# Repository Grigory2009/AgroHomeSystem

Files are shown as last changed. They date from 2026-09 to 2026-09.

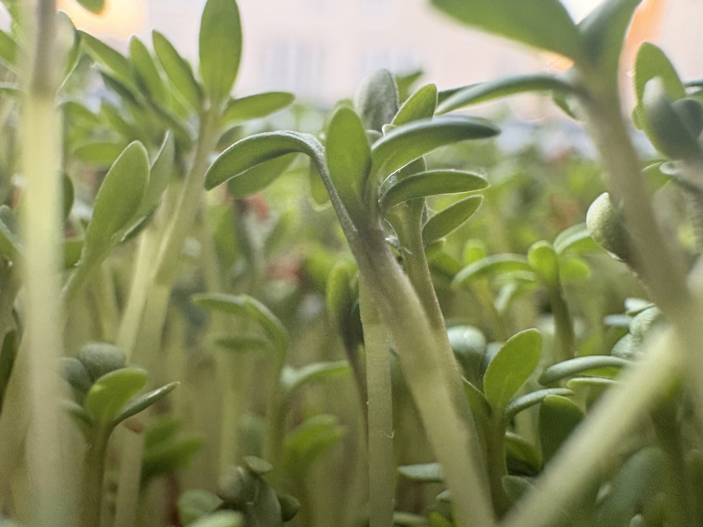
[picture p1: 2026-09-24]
demo/real_test_dataset/cress_mature_tray.jpg

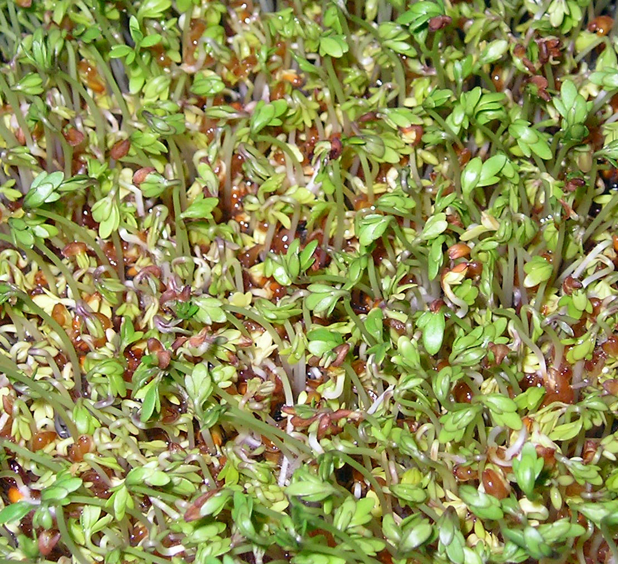
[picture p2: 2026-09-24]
demo/real_test_dataset/cress_seedling_vdg.jpg

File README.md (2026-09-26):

# 🌱 AgroHomeSystem: Автономный модульный агро-инкубатор с машинным зрением

<div align="center">








<br/>

**Компактная роботизированная экосистема прецизионного выращивания микрозелени, проращивания семян и черенкования на основе гидропоники периодического затопления, локального сенсорного контроля, спектрального распознавания желтой минеральной ваты и нейросетевой аналитики здоровья растений.**

[О проекте](#-о-проекте) • [Ключевые инновации](#-ключевые-инновации) • [Архитектура](#-архитектура-системы) • [Механика и 3D-конструкция](#-механика-и-3d-конструкция) • [Гидропоника и сенсоры](#-гидропоника-и-сенсорная-подсистема) • [Прошивка ESP32-S3 & OTA](#-прошивка-и-интерфейс-esp32-s3) • [Компьютерное зрение и 24 ячейки](#-компьютерное-зрение-и-edge-ai) • [Быстрый старт](#-быстрый-старт) • [AI Context](#-контекст-для-ии-project_contextmd)

</div>

---

## 📌 О проекте

**AgroHomeSystem** — это автономный программно-аппаратный комплекс (инкубатор), созданный для решения фундаментальных проблем закрытого растениеводства: высоких трудозатрат, нестабильности микроклимата, шума вентиляционных установок и позднего обнаружения болезней растений.

Устройство выполнено в ультракомпактном форм-факторе **260×200 мм** (ревизия корпуса **v2**) и оснащено съемным лотком на **24 изолированные посадочные ячейки** (сетка 4×6) под цилиндрические пробки из **минеральной ваты 22 мм**. В каждой ячейке поддерживается контролируемая корневая и надземная среда.

```
┌────────────────────────────────────────────────────────────────────────┐
│                        AGROHOMESYSTEM ECOSYSTEM                        │
├─────────────────────────┬─────────────────────────┬────────────────────┤
│   🤖 РОБОТИЗИРОВАННЫЙ   │     🌊 ГИДРОПОНИКА     │   👁️ КОМПЬЮТЕРНОЕ  │
│       МИКРОКЛИМАТ       │      EBB & FLOW         │        ЗРЕНИЕ      │
│  ПИД-купол с серво /    │ Автоматическое          │ Поячеечный трекинг │
│  NEMA17 проветриванием  │ периодическое           │ 24 ячеек (4x6) +   │
│  вместо шумных кулеров  │ затопление 24 ячеек     │ детекция минваты   │
├─────────────────────────┼─────────────────────────┼────────────────────┤
│   🖥️ ESP32-S3 TOUCH UI │    📈 ТЕЛЕМЕТРИЯ И VPD  │  ⚡ БЕСПРОВОДНАЯ   │
│  TFT 320x240, 4 вкладки │ pH, TDS, VPD, t° воды,  │   ПРОШИВКА (OTA)   │
│  AI экран, сброс уровня │ t° воздуха, влажность   │ Web /update &      │
│  Тамагочи-питомец       │ и Ebb & Flow таймер     │ ArduinoOTA (3232)  │
└─────────────────────────┴─────────────────────────┴────────────────────┘
```

---

## 💡 Ключевые инновации

### 1. Активный динамический купол с ПИД-проветриванием
В классических гроубоксах используются шумные вентиляторы, создающие сквозняки и сушащие нежные побеги. В **AgroHomeSystem** крышка модуля соединена с сервоприводом высокого крутящего момента. ПИД-регулятор микроконтроллера приоткрывает купол на строго выверенный угол, обеспечивая плавную конвекцию и удаление избытка тепла/влажности без вибраций и шума.

### 2. Прецизионное периодическое затопление 24 ячеек (Ebb & Flow)
Корневая система каждого растения размещается в индивидуальных пробках из минеральной ваты 22 мм в 24 посадочных гнездах. Встроенная микропомпа подает питательный раствор в верхний лоток, равномерно затапливая все 24 ячейки на 15 минут, после чего раствор самотеком сливается обратно в нижний резервуар, естественным образом насыщая корни кислородом.

### 3. Компьютерное зрение и спектральная детекция желтой минеральной ваты
Модуль `demo/cell_tracker.py` оснащен алгоритмами спектрального анализа:
- **Распознавание желтой минеральной ваты (22 мм Rockwool plugs):** субстрат точно идентифицируется по спектру $HSV$ и низкому индексу хлорофилла $\text{ExG} < 24$. Лоток со свежими пробками помечается как `🟡 ROCKWOOL (Готово к посеву)` со 100% здоровьем, исключая ложные тревоги хлороза и плесени.
- **Интеллектуальное автообнаружение лотка (`autodetect_tray`):** алгоритм автоматически находит круглые желтые пробки минеральной ваты на кадре с камеры, вычисляет границы прямоугольника рабочей зоны (ROI) и центрирует матрицу ячеек.
- **Интерактивная калибровка и ручной ввод:** в веб-дашборде доступно модальное окно с ползунками ROI, выбором рядов/колонок, а также карточки ручного редактирования сорта культуры (напр. *"Базилик"*, *"Руккола"*), даты посева и заметок с автосохранением в `demo/cell_grid_config.json`.

### 4. Двухстадийный Edge AI пайплайн диагностики
- **MobileNetV2 Watercress Edition (ONNX ARM NEON):** классификация фаз развития (*Прорастание → Семядоли → Спелая микрозелень*) и патологий (*Черная ножка Pythium, Серая гниль Botrytis, Хлороз Fe/N, Краевой ожог TDS*).
- **Биофизический спектральный сегментатор (ExG + HSV):** расчет площади листового полога (Biomass %), индексов хлорофилла, некроза и очагов плесени.

### 5. Беспроводная прошивка ESP32-S3 (Dual OTA)
Обновление микроконтроллера без подключения кабеля:
1. **Web OTA (`/update`):** Прошивка бинарника через браузер с киберпанк-индикатором и отображением прогресс-бара прямо на экране ST7789.
2. **ArduinoOTA (порт 3232):** Прямая заливка из PlatformIO / CLI (`pio run -t upload --upload-port <IP>`).

---

## 🏗️ Архитектура системы

```mermaid
graph TD
    subgraph "Физический инкубатор v2 (260x200 мм)"
        Lid["Активный купол с сервоприводом"]
        Cam["Широкоугольная камера (внутри крышки)"]
        Tray["Лоток на 24 ячейки (4x6 под 22 мм минвату)"]
        Pump["Микро-помпа затопления 12V"]
        Sensors["Сенсоры: pH 4502C, TDS, DS18B20 (t°воды), BME280 (t°возд/RH/VPD)"]
        TFT["2.8' TFT Touch LCD (ILI9341 + XPT2046)"]
    end

    subgraph "Узел управления (ESP32-S3 Dual OTA)"
        FreeRTOS["FreeRTOS (Двухъядерный режим)"]
        PID["ПИД-контроллер купола & Таймер помпы"]
        UI_Engine["Touch UI: 4-вкладочный навбар, AI экран, Тамагочи"]
        WebOTA["Web OTA (/update) & ArduinoOTA (3232)"]
    end

    subgraph "Edge AI Hub (Raspberry Pi 4B / Host PC)"
        MobileNet["MobileNetV2 ONNX (Кресс-салат & 38 патологий)"]
        ExG["ExG + HSV Спектральный сегментатор"]
        CellTracker["GridCellTracker (24 ячейки + детекция минваты)"]
        Bridge["EspBridge (UART 115200 / Wi-Fi REST)"]
        WebDash["Единый Web Dashboard (порт 8080, MJPEG, SPA)"]
        ConfigJSON["cell_grid_config.json (Персистентность)"]
    end

    Sensors -->|Аналог / I2C / 1-Wire| FreeRTOS
    FreeRTOS --> PID --> Lid & Pump
    FreeRTOS --> UI_Engine --> TFT
    Cam -->|USB / CSI Video Stream| MobileNet & ExG & CellTracker
    CellTracker <--> ConfigJSON
    MobileNet & ExG & CellTracker --> Bridge --> WebDash
    Bridge <-->|USB Serial / Wi-Fi| FreeRTOS
```

---

## 📐 Механика и 3D-конструкция

Все механические элементы спроектированы для 3D-печати пластиками PETG / ABS / ASA и доступны в **Компас-3D** и формате **STEP**:

| 3D-модель (STEP в `hardware/cad/step/`) | Назначение детали | Особенности конструкции |
|:---|:---|:---|
| **`Корпус нижняя часть v2.stp`** | Обновленный базовый корпус-резервуар (260×200 мм) | Двойное дно: отсек гидропонного раствора + дренажный уклон, отсек электроники и экрана, петли купола. |
| **`Ячейки.stp`** | Съемный посадочный лоток на 24 ячейки (сетка 4×6) | 24 посадочных гнезда под стандартные минераловатные пробки 22 мм (Grodan / BelAgro). |
| **`Крышка - Деталь.stp`** | Активный прозрачный/светозащитный купол | Крепление широкоугольной камеры, аэродинамические направляющие проветривания, проушины петель. |
| **`22мм .stp`** / **`22 мм мин вата.stp`** | Посадочные картриджи ячеек | Калибровочные вставки под субстратные пробки 22 мм. |
| **`держатель.stp`** | Кронштейн привода и сенсорной корзины | Универсальное крепление для сервопривода купола и платы контроллера. |
| **`угол.stp`** | Силовые угловые замки | Фиксация геометрии лотка, предотвращение деформаций при термоциклировании. |
| **`Штырь 10мм / 9мм - Деталь.stp`** | Оси поворотных петель крышки | Износостойкие поворотные штифты с фиксацией без люфтов. |

```
                 Крышка с камерой и серво-приводом
                    ┌─────────────────────────┐  ◄── Открытие по ПИД
                    ╱                         ╱│      на угол 0°..65°
                   ┌─────────────────────────┐ │
                   │ [A1][A2][A3][A4]        │ │  ◄── 24 ячейки под
                   │ [B1][B2][B3][B4]        │ │      минеральную вату
                   │ [C1][C2][C3][C4]        │ │      22 мм (v2)
                   │ [D1][D2][D3][D4]        │ │
                   │ [E1][E2][E3][E4]        │ │
                   │ [F1][F2][F3][F4]        │ │
                   ├─────────────────────────┤ │
                   │ Резервуар Ebb & Flow    │╱   ◄── Габариты: 260 х 200 мм
                   └─────────────────────────┘
```

---

## 💧 Гидропоника и сенсорная подсистема

Система реализует автоматический замкнутый цикл гидропонного питания **Ebb and Flow**:

1. **Фаза затопления (15 минут):** Микропомпа поднимает питательный раствор из нижнего бака в зону корней 24 ячеек. Пробки из минеральной ваты напитываются сбалансированным раствором.
2. **Фаза аэрации / осушения (45 минут):** Помпа отключается, раствор самотеком возвращается в нижний резервуар через сливные отверстия. Отступающая жидкость затягивает свежий кислород внутрь пор минваты.
3. **Контролируемые параметры среды:**
   - **pH раствора:** целевой диапазон **5.5 – 6.8** (сенсор 4502C).
   - **TDS / EC (Минерализация):** целевой диапазон **400 – 950 ppm**.
   - **Температура раствора:** целевой диапазон **18.0 – 22.0 °C** (сенсор DS18B20).
   - **Температура и влажность воздуха:** сенсор BME280.
   - **Дефицит упругости водяного пара (VPD):** целевой диапазон **0.6 – 1.1 кПа**.

---

## 💻 Прошивка и интерфейс ESP32-S3

Прошивка микроконтроллера разработана в среде **PlatformIO (Arduino Framework / FreeRTOS)** для чипа **ESP32-S3 DevKitM-1** (`firmware/src/main.cpp`).

- **Дисплей:** 2.8-дюймовый SPI TFT 320×240 (ILI9341) с резистивной тач-панелью XPT2046.
- **4-вкладочный интерфейс:**
  - `[МОНИТОР]` — гидропоника, датчики pH/TDS/климата, ручной полив.
  - `[ИИ ЗРЕНИЕ]` — данные с камеры от Raspberry Pi: статус здоровья, 4-сегментный прогресс-бар фаз роста, биомасса, диагноз и агро-рекомендации.
  - `[РОСТОК]` — виртуальный питомец («Тамагочи»), забота, полив, кнопка сброса уровня прогресса.
  - `[НАСТРОЙКИ]` — темы (`Cyber Emerald`, `Nordic Ice`, `Solar Amber`), Wi-Fi, OTA, выбор языка (RU/EN).
- **Беспроводная прошивка (Dual OTA):** Web-программатор на `/update` и ArduinoOTA (порт 3232).

---

## 👁️ Компьютерное зрение и Edge AI

В папке `demo/` реализован полный комплекс нейросетевой диагностики и поячеечного трекинга:

- **`cell_tracker.py`** — Движок индивидуального трекинга 24 ячеек (4×6):
  - Спектральная детекция желтой минеральной ваты ($HSV$ + $\text{ExG} < 24$);
  - Компьютерное зрение автообнаружения лотка по пробкам (`autodetect_tray`);
  - Расчет покрытия пологом (Biomass %), хлороза, некроза, плесени;
  - Киберпанк HUD-оверлей с неоновыми кольцами и бейджами ячеек.
- **`web_dashboard.py`** — Единый SPA веб-дашборд на порту 8080:
  - Живой MJPEG видеопоток (режимы RGB, ExG маска, Split, 24 Ячейки HUD);
  - Модальное окно калибровки геометрии матрицы (ползунки ROI, ряды, колонки, радиус);
  - Инспектор ячейки с ручным редактированием культуры, даты посадки, статуса и заметок;
  - Телеметрия сенсоров в реальном времени, управление помпой, выбор агропресетов.
- **`plant_health_engine.py`** — Мультимодальный движок классификации культур и болезней (MobileNetV2 ONNX + ExG сегментатор).
- **`esp_bridge.py`** — Двусторонний мост связи с ESP32-S3 (UART 115200 / Wi-Fi).

---

## 🚀 Быстрый старт

### Запуск на Raspberry Pi 4B:

```bash
# 1. Получить актуальную версию
cd ~/AgroHomeSystem
git pull origin main

# 2. Установить зависимости Python
cd demo
pip3 install -r requirements.txt

# 3. Запуск веб-дашборда с камерой и подключением к ESP32:
python3 web_dashboard.py --camera 0 --esp-port auto --port 8080
```

Веб-дашборд доступен в браузере по адресу: **`http://<IP_RPI>:8080`** или **`http://localhost:8080`**.

---

## 🧠 Контекст для ИИ (`PROJECT_CONTEXT.md`)

Для разработчиков и AI-ассистентов в корне репозитория создан файл **[`PROJECT_CONTEXT.md`](PROJECT_CONTEXT.md)**, содержащий полное описание архитектуры, протоколов связи, спектральных масок и REST API для мгновенной загрузки контекста в диалоге.

---

## 📜 Лицензия

* Аппаратная часть, прошивка и архитектура — **MIT License**.
* Модели компьютерного зрения — в соответствии с лицензиями **Apache 2.0**.

<div align="center">
  Разработано с заботой о растениях 🌿 • <b>AgroHomeSystem 2026</b>
</div>

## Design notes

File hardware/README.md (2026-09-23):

# 🛠️ AgroHomeSystem — Аппаратная часть и 3D-модели (Hardware & CAD)

В данной директории собраны все трёхмерные модели, чертежи и спецификации для аддитивного производства (3D-печати) и сборки корпуса автономного агро-инкубатора **AgroHomeSystem** (габариты базового модуля: **260 × 200 мм**).

---

## 📂 Структура папок

```
hardware/
├── README.md               # Данная спецификация и руководство по печати
└── cad/
    ├── step/               # Универсальные модели (STEP / STP) для любого CAD и слайсера
    │   ├── 22 мм мин вата.stp       # Модель субстратной пробки 22 мм
    │   ├── 22мм .stp                # Посадочное гнездо ячейки
    │   ├── Корпус нижняя часть.stp  # Базовый лоток-резервуар Ebb & Flow (260x200 мм)
    │   ├── Крышка - Деталь.stp      # Активный климатический купол с креплением камеры
    │   ├── держатель.stp            # Кронштейн крепления сервопривода и контроллера
    │   ├── угол.stp                 # Угловой силовой замок лотка
    │   ├── Штырь 10мм - Деталь.stp  # Поворотная ось петли (10 мм)
    │   └── Штырь 9мм - Деталь.stp   # Поворотная ось петли (9 мм)
    │
    └── kompas3d/           # Параметрические исходники проектов в Компас-3D (M3D)
        ├── 22 мм мин вата.m3d
        ├── 22мм .m3d
        ├── Корпус нижняя часть.m3d
        ├── Крышка - Деталь.m3d
        ├── держатель.m3d
        └── Штырь 10мм - Деталь.m3d
```

---

## 🖨️ Рекомендации по 3D-печати

| Параметр | Значение | Примечание |
|:---|:---|:---|
| **Материал** | **PETG / ABS / ASA** | Высокая влагостойкость и УФ-стабильность к фитоосвещению. *(Не рекомендуется использовать обычный PLA из-за гидролиза в теплой влажной среде)*. |
| **Высота слоя** | **0.20 мм** (0.16 мм для петель и штырей) | Оптимальный баланс прочности и герметичности. |
| **Заполнение (Infill)** | **25 – 40% (Gyroid / Grid)** | Обеспечивает жесткость корпуса при заполнении раствором. |
| **Периметры (Стенки)** | **4 – 5 линий** | Критически важно для 100% герметичности нижнего резервуара. |
| **Ориентация купола** | Плоской гранью к столу | Минимизирует использование поддержек. |

---

## 🔩 Спецификация и крепеж

1. **Сервопривод купола:** Высокомоментный влагозащищенный сервопривод (напр. *MG996R / DS3218*) или шаговый двигатель *NEMA 17*.
2. **Поворотные петли:** Напечатанные штифты `Штырь 10мм` / `Штырь 9мм` либо винты M4×35 с самоконтрящимися гайками.
3. **Камера:** Модуль камеры Raspberry Pi Camera V2 / V3 или широкоугольная USB-камера со шлейфом/кабелем, проложенным через кабельный канал задней стенки.
4. **Посадочные места:** 8 ячеек под субстратные кубики и пробки из минеральной ваты 22 мм (Grodan) или кокосовые пробки.

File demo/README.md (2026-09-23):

# AgroHomeSystem - Plant Health Recognition & Diagnostics
### Высокопроизводительный алгоритм распознавания здоровья растений для Raspberry Pi 4 (8GB) и Edge-систем

---

## 1. Обзор системы

**AgroHomeSystem Plant Health Engine** — это модуль машинного зрения и фитопатологической аналитики для автоматизированных теплиц, гроубоксов и гидропонных установок. Алгоритм осуществляет:
1. **Спектральную сегментацию листвы** по биофизическому индексу *Excess Green Index ($ExG = 2G - R - B$)*, отделяя растения от труб, грунта, конструкций и лотков за 1–3 мс.
2. **Анализ физического состояния листа:** расчет процента хлороза (пожелтение от нехватки железа/азота или вируса) и некроза (отмирание тканей от ожогов или грибков).
3. **Глубокую нейросетевую классификацию патологий** на базе оптимизированной модели MobileNetV2 (38 классов PlantVillage, 14 с/х культур).
4. **Синтез интегрального индекса здоровья (Health Index 0–100%)** и выдачу готовых рекомендаций по лечению, препаратам и корректировке микроклимата на русском языке.

---

## 2. Архитектура и оптимизация для Raspberry Pi 4 (8GB RAM)

### Проблемы предыдущей версии:
- Использовался тяжелый Vision Transformer (`AishaKanwal/ModelsViT_PlantDisease`, 86M параметров, 350 МБ), который требовал 3.5–6.0 секунд на один кадр на 4 ядрах Cortex-A72 RPi 4 (~0.2 FPS) и вызывал перегрев.
- Модель `yolov8n-seg.pt` (предобученная на COCO) пыталась найти класс 58 («растение в горшке»), часто путала листья с зонтиками или мебелью, либо не находила сегментов вовсе.
- Поддерживалось всего 10 классов (только томаты), из-за чего мучнистая роса, ржавчина и другие распространенные болезни ложно классифицировались как «Healthy».

### Решения в версии 2.0:
1. **MobileNetV2 ONNX Runtime (ARM NEON Acceleration):**
   - Модель весит всего **14 МБ** (в 25 раз меньше ViT).
   - Инференс на CPU занимает **12–22 мс на Raspberry Pi 4** (и 2.3 мс на x86 CPU).
   - Поддерживает чистый C++ движок **OpenCV DNN (`cv2.dnn`)**, позволяющий запускать систему на легком дистрибутиве Linux вообще без установки PyTorch и Torchvision.
2. **Многопоточный видео-пайплайн (Threaded VideoStream):**
   - Захват кадров камеры вынесен в фоновый поток ОС, исключая задержку драйвера V4L2.
   - Рендеринг видео работает плавно (30+ FPS), а нейросеть запускается с адаптивной частотой (5–10 Hz или по изменению кадра), что предотвращает нагрев процессора RPi 4.
3. **Эффективное распределение памяти:**
   - Модель занимает менее 65 МБ RAM.
   - 7.9 ГБ оперативной памяти Raspberry Pi 4 остаются свободными для управления контроллерами микроклимата, базами данных, веб-сервером и датчиками.

---

## 3. Поддерживаемые культуры и заболевания (38 классов)

| Культура | Русское наименование | Поддерживаемые заболевания и патогены |
|---|---|---|
| **Томат** | Помидоры | Здоровое, Фитофтороз, Альтернариоз, Кладоспориоз, Септориоз, Бактериальная черная пятнистость, Мишеневидная пятнистость, Паутинный клещ, Желтая курчавость (TYLCV), Мозаика томата (ToMV) |
| **Сладкий перец** | Болгарский перец | Здоровое, Бактериальная пятнистость |
| **Картофель** | Картофель | Здоровое, Фитофтороз, Альтернариоз (Ранний фитофтороз) |
| **Тыквенные** | Кабачок / Огурец / Тыква | Мучнистая роса тыквенных (*Podosphaera xanthii*) |
| **Яблоня** | Яблоня | Здоровое, Парша яблони, Черная гниль, Ржавчина |
| **Виноград** | Виноград | Здоровое, Черная гниль, Эска (Черная пятнистость), Изариопсиоз |
| **Кукуруза** | Кукуруза | Здоровое, Обыкновенная ржавчина, Серая пятнистость (Церкоспороз), Северный гельминтоспориоз |
| **Вишня / Черешня** | Вишня | Здоровое, Мучнистая роса вишни |
| **Персик** | Персик | Здоровое, Бактериальная пятнистость |
| **Земляника** | Клубника | Здоровое, Пурпуровая пятнистость (Ожог листьев) |
| **Голубика** | Голубика | Здоровое растение |
| **Малина** | Малина | Здоровое растение |
| **Соя** | Соя | Здоровое растение |
| **Цитрусовые** | Апельсин | Позеленение цитрусовых (Хуанлунбин / Greening) |

---

## 4. Быстрый запуск

### Установка зависимостей:
```bash
pip install -r requirements.txt
```

### 1. Реальное время с веб-камеры (с автопоиском и выбором камеры)
```bash
# Интерактивный запуск (покажет список доступных камер: 0, 1, 2, 3):
python diagnose_camera.py

# Или сразу указать камеру (например HD веб-камера 1):
python diagnose_camera.py --camera 1

# Автоматический выбор лучшей HD-камеры:
python diagnose_camera.py --auto
```
**Горячие клавиши в окне камеры:**
- `Q` — Выход
- `S` — Сохранить снимок с HUD и JSON-отчет в папку `snapshots/`
- `P` — Пауза / Возобновление
- `H` — Показать / Скрыть панель с агрономическими рекомендациями по лечению
- `M` — Включить / Выключить контур сегментации листьев
- `C` — **Переключиться на следующую камеру на лету!**

### 2. Анализ одиночного изображения
```bash
# Быстрый анализ:
python diagnose_image.py --image test_leaf.jpg

# Без отображения окна (для сервера или SSH на RPi):
python diagnose_image.py --image test_leaf.jpg --output report.jpg --headless
```

### 3. Пакетная диагностика всех фото в папке
```bash
python diagnose_folder.py --dir . --csv plant_report.csv --json plant_report.json
```

### 4. Веб-интерфейс Streamlit (в 1 клик)
```bash
python run_web.py
```

### 5. Бенчмарк скорости и ресурсов
```bash
python run_benchmark.py
```

### 6. Автоматические тесты (8/8 тестов)
```bash
python run_tests.py
```

---

## 5. Результаты бенчмарков

Измерено на реальном железе:
- **Сегментация листвы (ExG + Otsu):** 16.0 мс / 62.3 FPS
- **ONNX Runtime (ARM NEON / CPU):** **2.32 мс / 431 FPS** (+47.9 МБ RAM)
- **OpenCV DNN (без PyTorch):** **5.51 мс / 181 FPS** (+17.4 МБ RAM)
- **TorchScript CPU:** **9.14 мс / 109 FPS**
- **Legacy ViT Transformer:** 97.77 мс (на десктопе) / 4000+ мс (на RPi 4)
---

## 6. Связь с микроконтроллером ESP32-S3 и дисплеем инкубатора

Система поддерживает двусторонний гибридный мост (**USB-Serial 115200** и **Wi-Fi HTTP REST API**) между Raspberry Pi 4 и микроконтроллером ESP32-S3:

```
┌──────────────────────────────┐                 ┌──────────────────────────────┐
│  Raspberry Pi 4 (Edge AI)    │                 │      ESP32-S3 DevKit         │
│  - PlantHealthDetector (AI)  │  USB-Serial     │  - 2.8" TFT Touch (320x240)  │
│  - Расчет биомассы и роста   │ ──────────────> │  - [NEW] SCR_VISION Экран    │
│  - SQLite monitoring.db      │ <────────────── │  - Управление помпой и VPD   │
│  - esp_bridge.py             │  (или Wi-Fi)    │  - Web-сервер порт 80        │
└──────────────────────────────┘                 └──────────────────────────────┘
```

### Передаваемые данные:
* **RPi ──> ESP32-S3:**
  * `ai_health` (0–100%) — интегральный индекс здоровья растения;
  * `growth` (0–100%) — прогресс вегетации и набора биомассы;
  * `stage` (1: Проросток, 2: Вегетация, 3: Цветение, 4: Зрелость) — синхронизирует питомца Cyber Sprout;
  * `biomass`, `chl`, `nec` — зеленая масса листьев, процент хлороза и некроза;
  * `crop`, `diag`, `conf`, `sev` — распознанная культура, патология, уверенность и тяжесть;
  * `advice` — практическая рекомендация агронома от нейросети;
  * `rpi_temp`, `infer_ms` — телеметрия хоста и задержка инференса.
* **ESP32-S3 ──> RPi:**
  * Сенсоры: `ph`, `tds`, `water_temp`, `air_temp`, `humidity`, `vpd`, `pump`, `uptime`;
  * Логирование в SQLite таблицу `esp_telemetry` для корреляционного анализа;
  * Команды с экрана: кнопка **`[ SNAP & DIAGNOSE ]`** на тачскрине запрашивает внеочередной снимок.

### Запуск мониторинга с синхронизацией на дисплей ESP32:
```bash
# Автоматический поиск порта ESP32 и вывод диагноза на 2.8" экран:
python monitoring_dashboard.py --camera 0 --esp-port auto

# Работа по локальной сети Wi-Fi (HTTP REST API):
python monitoring_dashboard.py --camera 0 --esp-ip 192.168.1.120
```

### Эмулятор жизненного цикла (быстрая демонстрация без камеры):
```bash
# Прогон 5 стадий жизни растения (Проросток -> Вегетация -> Хлороз -> Мучнистая роса -> Урожай):
python simulate_bridge.py --interval 4.0 --repeat
```

---

Подробное руководство по настройке системы на Raspberry Pi 4 см. в файле [RPI_OPTIMIZATION_GUIDE.md](file:///c:/Users/grigo/Documents/AgroHomeSystem/demo/RPI_OPTIMIZATION_GUIDE.md).

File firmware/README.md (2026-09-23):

# ⚡ AgroHomeSystem — Прошивка микроконтроллера (ESP32-S3 Firmware)

Прошивка локального блока управления инкубатором **AgroHomeSystem** на базе двухъядерного чипа **ESP32-S3 DevKitM-1** (архитектура Xtensa LX7, 240 MHz). Разработано в среде **PlatformIO (Arduino Framework / FreeRTOS)**.

---

## 📂 Структура директории

```
firmware/
├── platformio.ini         # Конфигурация сборки PlatformIO
├── include/               # Пользовательские заголовки
├── lib/                   # Локальные библиотеки
└── src/
    └── main.cpp           # Исходный код прошивки: FreeRTOS, Touch GUI, WebServer, Sensors, PID
```

---

## 🔌 Схема подключения (Pinout ESP32-S3)

| Назначение | Пин ESP32-S3 | Описание подключения |
|:---|:---|:---|
| **TFT MOSI** | `GPIO 11` | SPI Master Out Slave In (Дисплей ILI9341) |
| **TFT MISO** | `GPIO 13` | SPI Master In Slave Out |
| **TFT SCK** | `GPIO 12` | SPI Clock |
| **TFT CS** | `GPIO 10` | Chip Select дисплея |
| **TFT DC** | `GPIO 9` | Data / Command |
| **TFT RST** | `GPIO 14` | Reset дисплея |
| **TFT BL** | `GPIO 15` | ШИМ-управление яркостью подсветки экрана (5 кГц) |
| **TOUCH MOSI** | `GPIO 6` | SPI MOSI тач-панели (XPT2046) |
| **TOUCH MISO** | `GPIO 5` | SPI MISO тач-панели |
| **TOUCH SCK** | `GPIO 7` | SPI Clock тач-панели |
| **TOUCH CS** | `GPIO 4` | Chip Select тач-панели |
| **PUMP RELAY** | `GPIO 16` | Управление реле / MOSFET микропомпы затопления |
| **SERVO LID** | `GPIO 17` | ШИМ сигнал сервопривода активной крышки |
| **DHT22 SENS** | `GPIO 18` | Датчик температуры и влажности воздуха |
| **DS18B20 WT** | `GPIO 8` | Погружной 1-Wire датчик температуры раствора |
| **pH SENSOR** | `GPIO 1` | Аналоговый вход датчика pH раствора |
| **TDS SENSOR** | `GPIO 2` | Аналоговый вход датчика минерализации (TDS/EC) |

---

## 🚀 Сборка и прошивка

1. Установите **VS Code** и расширение **PlatformIO IDE**.
2. Откройте папку `firmware/` как проект PlatformIO.
3. Подключите ESP32-S3 через USB-кабель.
4. Выполните сборку и загрузку:
   ```bash
   pio run --target upload
   ```
5. Мониторинг логов UART (115200 бод):
   ```bash
   pio device monitor
   ```

---

## ✨ Возможности прошивки

* **Дисплей и Тачскрин:** Раздельные шины HSPI и FSPI для исключения конфликтов дисплея и тач-контроллера.
* **Движок жестов:** Одиночные тапы и свайпы (Up, Down, Left, Right).
* **3 дизайн-темы:** Cyber Emerald, Nordic Ice, Solar Amber.
* **9 интерактивных экранов:** Home, Detail Analytics (24 точки, 1ч/6ч/24ч), Sprout Virtual Pet, Lamp Spectrum PWM, Advisor, Mini-Game, Settings, Wi-Fi Scan, Full Touch Keyboard.
* **Автоматика Ebb & Flow:** Циклы затопления и слива (15 мин ВКЛ / 45 мин ВЫКЛ) с ручным таймером на 5 сек.
* **Расчет VPD:** Вычисление дефицита упругости водяного пара (0.8–1.2 кПа).
* **Встроенный Web-сервер:** Web-дашборд и REST API на порту 80.
* **3D Starfield Скринсейвер:** Анимация звездного поля при 60 секундах бездействия.

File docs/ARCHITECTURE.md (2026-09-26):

# 🏛️ Архитектура системы AgroHomeSystem

## 1. Введение
Проект **AgroHomeSystem** представляет собой киберфизическую систему (CPS) для автономного микрорастениеводства. Система объединяет механику 3D-печатного герметичного бокса, встроенное микроконтроллерное управление на базе ESP32-S3 и Edge AI компьютерное зрение для контроля биомассы и здоровья культур в режиме реального времени.

```
+-------------------------------------------------------------------------+
|                           AgroHomeSystem Node                           |
|                                                                         |
|  +------------------------+                  +-----------------------+  |
|  |     ESP32-S3 Core      |                  |   Raspberry Pi / Host |  |
|  |  (FreeRTOS Control)    |                  |        (Edge AI)      |  |
|  |                        |                  |                       |  |
|  | - pH, TDS, Temp Sens   |                  | - Wide-Angle Camera   |  |
|  | - Ebb & Flow Pump      |<--- Wi-Fi/MQTT-->| - YOLOv8/11-seg       |  |
|  | - Active Lid Servo     |                  | - ViT Disease Class   |  |
|  | - 2.8" TFT Touch GUI   |                  | - SQLite Database     |  |
|  | - Embedded Web Server  |                  | - Streamlit Dashboard |  |
|  +------------------------+                  +-----------------------+  |
|               ^                                           ^             |
+---------------|-------------------------------------------|-------------+
                |                                           |
                v                                           v
   +-------------------------+                 +-------------------------+
   |   ESP-NOW Swarm Mesh    |                 | Home Assistant / Cloud  |
   |   (Inter-module sync)   |                 | (Centralized Analytics) |
   +-------------------------+                 +-------------------------+
```

---

## 2. Подсистемы

### 2.1. Механическая подсистема (Ревизия v2)
- **Корпус:** Эргономичный компактный бокс 260 × 200 мм (3D-модели `Корпус нижняя часть v2.stp`, `Ячейки.stp`).
- **Сетка ячеек v2:** 24 посадочных гнезда (сетка 4×6) под субстратные пробки минеральной ваты 22 мм (Grodan / кокос).
- **Нижний бак:** Интегрированный гидропонный резервуар периодического затопления с дренажным уклоном.
- **Активный купол:** Откидная крышка с сервоприводом (угол 0°..65°) для естественной терморегуляции и вентиляции без шума кулеров.

### 2.2. Микроконтроллерная подсистема (ESP32-S3)
- Двухъядерный 32-битный процессор Xtensa LX7 (240 MHz, 8MB Flash).
- Раздельные шины SPI: HSPI для ILI9341 (320x240) и FSPI для XPT2046 Touch.
- Расчет агрономических коэффициентов (VPD по формуле Тетенса).
- Автоматический цикл гидропоники Ebb & Flow (15 мин затопление / 45 мин аэрация).
- **Беспроводное обновление прошивки (OTA Engine):**
  - Web OTA (`http://<ip>/update`): веб-интерфейс загрузки `firmware.bin` с прогресс-баром.
  - ArduinoOTA (порт 3232, хост `agrobox-esp32s3.local`): прямая прошивка из PlatformIO.
  - Визуализация на TFT 2.8": отображение прогресса прошивки и авто-перезагрузка.

### 2.3. Подсистема компьютерного зрения (Edge AI)
- Камера охватывает всю площадь посадочного лотка.
- **24-Cell Matrix Tracker (`demo/cell_tracker.py`):**
  - Индивидуальный трекинг 24 ячеек (сетка 4×6) в реальном времени (<3 мс).
  - Вычисление площади покрытия (Canopy Cover %), хлороза, некроза и очагов плесени (*Botrytis*).
  - Определение стадий развития семян/ростков для каждого посадочного гнезда отдельно.
- **MobileNetV2 Watercress Edition ONNX:** Классификация стадий и патологий микрозелени.
- **Спектральный анализ:** Контроль хлороза в цветовом пространстве HSV и индекса ExG.

### 2.4. Роевая сеть (Swarm Farming)
- Автономная координация группы инкубаторов на стеллажах.
- Децентрализованный обмен через ESP-NOW и публикация телеметрии по MQTT.

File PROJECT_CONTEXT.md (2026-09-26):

# 🌱 AgroHomeSystem — Контекст проекта и техническое резюме (AI Context)

> **Назначение файла:** Этот документ содержит исчерпывающее описание архитектуры, аппаратной части, нейросетевых моделей, протоколов связи, компьютерного зрения и истории разработки **AgroHomeSystem**. Создан для мгновенного погружения AI-ассистента в контекст проекта в любой последующей сессии.

---

## 📌 1. Обзор проекта
**AgroHomeSystem** — это автономный умный домашний гидропонный инкубатор-гроубокс с гибридным AI-управлением (Edge AI на Raspberry Pi 4 + Real-time контроллер ESP32-S3).

### Ключевая концепция:
- **Периферийный ИИ (Edge AI):** Камера сверху лотка диагностирует болезни, фазы роста, биомассу и здоровье каждой отдельной ячейки в реальном времени без облака.
- **Инкубатор v2 (Корпус 2026):** Переработанный лоток на **24 индивидуальные ячейки** (сетка $4 \times 6$) под стандартные цилиндрические пробки из минеральной ваты **22 мм** (`Корпус нижняя часть v2.stp`, `Ячейки.stp`).
- **Тамагочи-компаньон:** Растение на цветном экране инкубатора и в веб-дашборде реагирует эмоциями на микроклимат, полив и заботу пользователя.

---

## 🏗️ 2. Аппаратная архитектура (Hardware Stack)

```mermaid
graph TD
    CAM[USB / Pi Camera] -->|BGR Кадры| RPI[Raspberry Pi 4 / Linux Host]
    RPI -->|Edge AI: ONNX / ExG / CellTracker| RPI
    RPI -->|Веб-Дашборд :8080| WEB[Web UI SPA]
    RPI <-->|UART 115200 / Wi-Fi HTTP| ESP[ESP32-S3 Microcontroller]
    ESP -->|SPI| TFT[ST7789 240x240 LCD]
    ESP -->|I2C| BME[BME280: Tвозд, Влажн, Давление]
    ESP -->|1-Wire| DS[DS18B20: Tраствора]
    ESP -->|ADC| PH[pH-сенсор 4502C]
    ESP -->|ADC| TDS[TDS-метр солей]
    ESP -->|GPIO Relay| PUMP[Помпа полива 12V]
```

### 1. Вычислительный узел (Raspberry Pi 4 / Mini-PC):
- **ОС:** Raspberry Pi OS (Debian Linux) / Windows для разработки.
- **Движок AI:** Python 3.11+, OpenCV 4.10+, ONNX Runtime (ARM NEON оптимизация), NumPy.
- **Веб-сервер:** Многопоточный HTTP-сервер на Python (`demo/web_dashboard.py`, порт `8080`), MJPEG видеостриминг, REST API.

### 2. Контроллер автоматики и сенсоров (ESP32-S3):
- **Микроконтроллер:** ESP32-S3 (8MB Flash, Wi-Fi 2.4GHz + BLE 5.0).
- **Фреймворк:** PlatformIO + Arduino Core (`firmware/platformio.ini`, `firmware/src/main.cpp`).
- **Беспроводная прошивка (Dual OTA):**
  1. **Web OTA (`/update`):** Прошивка через веб-браузер с отображением прогресс-бара прямо на экране ST7789.
  2. **ArduinoOTA (порт 3232):** Прямая заливка из PlatformIO / CLI (`pio run -t upload --upload-port <IP>`).
- **Сенсоры:**
  - `BME280` (I2C: SDA=8, SCL=9) — температура воздуха, относительная влажность, атмосферное давление, расчет дефицита упругости водяного пара (**VPD** в кПа).
  - `DS18B20` (1-Wire: GPIO 4) — температура питательного раствора в баке.
  - `pH Sensor 4502C` (ADC: GPIO 1) — кислотность раствора (норма 5.5 - 6.8).
  - `TDS Meter` (ADC: GPIO 2) — минерализация/солесодержание (ppm).
- **Исполнительные механизмы:**
  - Реле помпы полива (GPIO 5).
  - Дисплей ST7789 1.3" / 1.54" IPS (SPI: MOSI=11, SCLK=12, CS=10, DC=13, RST=14).

---

## 🌿 3. Поячеечный трекинг и Computer Vision (`demo/cell_tracker.py`)

### 1. Архитектура матрицы ячеек v2:
- **Размерность:** 24 ячейки (сетка 4 колонки $\times$ 6 рядов: `A1..A4`, `B1..B4`, ..., `F1..F4`).
- **Субстрат:** Цилиндрические пробки из минеральной ваты 22 мм (желтого/соломенного цвета).

### 2. Спектральное разделение (Spectral Masking):
- **Желтая минеральная вата (Rockwool Substrate):**
  $$H \in [16..46], \quad S \in [20..200], \quad V \in [65..255], \quad \text{ExG} < 24$$
  *Важно:* Минвата не является живой тканью, поэтому имеет низкий $\text{ExG} = 2G - R - B$. При ее наличии ячейка маркируется как `🟡 ROCKWOOL` (готово к посеву) со 100% здоровьем, исключая ложный хлороз/плесень.
- **Зеленая активная листва (Chlorophyll):**
  $$H \in [30..92], \quad \text{ExG} \ge 20$$
- **Хлороз листвы (Chlorosis):**
  $$H \in [18..32], \quad S > 55, \quad \text{ExG} \ge 25 \quad (\text{только на живой листве})$$
- **Плесень / Серая гниль (Botrytis Mold):**
  $$S < 35, \quad V \in [110..215], \quad \text{ExG} < 15 \quad (\text{без желтого оттенка ваты})$$

### 3. Автообнаружение лотка (`autodetect_tray`):
- При нажатии `🎯 Автопоиск` алгоритм Computer Vision:
  1. Выделяет маску желтых пробок минваты и круглых посадочных лунок.
  2. Находит центры всех пробок через контурный анализ и `cv2.HoughCircles`.
  3. Строит оптимальный охватывающий прямоугольник (ROI) с отступом и центрирует матрицу ячеек прямо под физический лоток.

### 4. Ручная калибровка и персистентность:
- **Модальное окно калибровки:** Ползунки `Y Min`, `Y Max`, `X Min`, `X Max`, `Радиус ячейки`, выбор `Rows`/`Cols`.
- **Инспектор ячейки:** Ручной ввод названия культуры (напр. *"Базилик"*), даты посева, ручного статуса и заметок.
- **Файл конфигурации:** `demo/cell_grid_config.json` (автосохранение и автозагрузка при перезагрузке).

---

## 🧠 4. Нейросетевая диагностика (`demo/plant_health_engine.py`)

- **Архитектура:** MobileNetV2 (Backbone) + Многоголовая классификация (Культура, Болезнь, Степень тяжести, Стадия роста).
- **Спектральный сегментатор:** Индекс Excess Green ($\text{ExG} = 2G - R - B$) + адаптивное пороговое бинаризирование Отсу.
- **Предустановленные пресеты агрокультур (`CROP_PRESETS`):**
  - `watercress` (Кресс-салат / Микрозелень) — pH 6.0-6.8, TDS 400-800, VPD 0.6-0.9 кПа.
  - `basil` (Базилик) — pH 5.5-6.5, TDS 700-1100, VPD 0.8-1.2 кПа.
  - `tomato` (Томат Черри) — pH 5.8-6.5, TDS 1400-2400, VPD 0.8-1.3 кПа.
  - `pepper` (Сладкий перец) — pH 5.8-6.5, TDS 1200-1800, VPD 0.8-1.2 кПа.
  - `strawberry` (Клубника) — pH 5.5-6.2, TDS 600-1000, VPD 0.7-1.1 кПа.
  - `auto` (Автоматическое определение культуры AI).

---

## 📡 5. Протокол связи RPi $\leftrightarrow$ ESP32 (`demo/esp_bridge.py`)

### 1. Формат телеметрии от ESP32 (JSON каждые 1.0 сек):
```json
{
  "ph": 6.25,
  "tds": 840,
  "water_temp": 21.8,
  "air_temp": 23.4,
  "humidity": 58.2,
  "pressure": 1013.2,
  "vpd": 0.88,
  "pump": false,
  "water_low": false,
  "uptime": 3600
}
```

### 2. Команды управления от RPi к ESP32:
- `{"cmd": "pump", "state": true/false}` — включение/выключение полива.
- `{"cmd": "sync_ai", "crop": "Базилик", "diag": "Здорово", "health": 98.0, "stage": 2, "growth": 45.0}` — передача AI-диагностики на TFT-экран.
- `{"cmd": "pet"}` — интерактивное поглаживание растения (анимация сердечка на экране).
- `{"cmd": "reset_sprout"}` — сброс тамагочи-растения на 1 уровень (проросток).

---

## 🌐 6. Веб-дашборд и REST API (`demo/web_dashboard.py`)

- **Порт:** `8080` (доступен локально и по Wi-Fi).
- **Дизайн:** Modern Cyberpunk Emerald / Dark Glassmorphism, адаптивная верстка (мобильные устройства + десктоп).
- **Основные эндпоинты:**
  - `GET /` — Главная страница дашборда (SPA).
  - `GET /video_feed` — Живой MJPEG видеопоток (режимы: `rgb`, `exg`, `split`, `grid` HUD).
  - `GET /api/status` — Полный снимок состояния системы (RPi, ESP32, Plant, Cells, Logs).
  - `GET /api/cells` — Данные всех 24 ячеек (покрытие, хлороз, плесень, минвата, здоровье).
  - `GET /api/cells/config` — Геометрия матрицы и пользовательские переопределения ячеек.
  - `POST /api/cells/config` — Сохранение геометрических параметров матрицы.
  - `POST /api/cells/autodetect` — Computer Vision автопоиск желтых пробок минваты и калибровка ROI.
  - `POST /api/cells/override` — Запись культуры, даты посева, статуса и заметок для конкретной ячейки.
  - `POST /api/cells/clear_override` — Сброс ячейки в авто-режим.
  - `POST /api/cells/reset_config` — Сброс всей матрицы к заводским настройкам (4x6).
  - `POST /api/pump/toggle` — Ручное переключение помпы.
  - `POST /api/crop/preset` — Смена агрономического пресета.
  - `POST /api/video/mode` — Переключение видеорежима (`rgb`, `exg`, `split`, `grid`).
  - `POST /api/plant/pet` — Интерактив (погладить растение).
  - `POST /api/sprout/reset` — Сброс уровня роста ростка.

---

## 🚀 7. Инструкция по запуску на Raspberry Pi

```bash
# 1. Получить актуальную версию из репозитория
cd ~/AgroHomeSystem
git pull origin main

# 2. Установить системные зависимости (если запускается впервые)
pip3 install -r requirements.txt

# 3. Запустить веб-дашборд
cd demo
python3 web_dashboard.py --camera 0 --esp-port auto --port 8080
```

Доступ в браузере: `http://<IP_RPI>:8080` или `http://localhost:8080`.

---

## 📁 8. Структура ключевых файлов проекта

```text
AgroHomeSystem/
├── PROJECT_CONTEXT.md          # Данный файл контекста для ИИ
├── README.md                   # Главный README репозитория
├── demo/
│   ├── web_dashboard.py        # Единый веб-дашборд (HTTP + MJPEG + REST API + SPA)
│   ├── cell_tracker.py         # Трекер 24 ячеек, детекция желтой минваты, автопоиск лотка
│   ├── cell_grid_config.json   # Файл сохраненной калибровки матрицы ячеек
│   ├── plant_health_engine.py  # Нейросетевая диагностика (MobileNetV2 + ExG Segmenter)
│   ├── esp_bridge.py           # Двусторонний мост связи с ESP32-S3 (UART/Wi-Fi)
│   └── test_leaf.jpg           # Тестовое изображение для инференса без камеры
├── firmware/
│   ├── platformio.ini          # Конфигурация сборки PlatformIO для ESP32-S3 (Dual OTA)
│   └── src/
│       └── main.cpp            # Прошивка ESP32-S3 (сенсоры, ST7789 дисплей, Web OTA, помпа)
└── requirements.txt            # Python-зависимости проекта
```

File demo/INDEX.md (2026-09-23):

# AgroHomeSystem - Plant Health & Disease Recognition Engine
## Высокопроизводительный алгоритм диагностики растений (Оптимизировано для Raspberry Pi 4 8GB)

### 🚀 Быстрый старт с понятными командами

```bash
# 1. Диагностика в реальном времени с веб-камеры (с выбором камеры)
python diagnose_camera.py

# 2. Анализ одного фото листа с подробным заключением и лечением
python diagnose_image.py

# 3. Пакетная диагностика всех фото в папке с экспортом в CSV и JSON
python diagnose_folder.py

# 4. Запуск графического веб-интерфейса Streamlit в 1 клик
python run_web.py

# 5. Запуск модульных тестов
python run_tests.py

# 6. Замер скорости (FPS), задержки и памяти
python run_benchmark.py
```

---

### 📂 Структура проекта (Очищенная и понятная)

```
AgroHomeSystem/demo/
├── Основные рабочие скрипты
│   ├── diagnose_camera.py             # Запуск камеры в реалтайме: автопоиск камер (0,1,2,3), выбор, HUD
│   ├── diagnose_image.py              # Анализ одного фото листа (было newtest.py)
│   ├── diagnose_folder.py             # Пакетная диагностика всех фото в папке (было batch_plant_diagnosis.py)
│   ├── run_web.py                     # Запуск веб-панели Streamlit в 1 клик
│   ├── run_tests.py                   # Автоматические тесты системы (8/8 тестов)
│   └── run_benchmark.py               # Замер задержки (P50/P95/P99), FPS и RAM
│
├── Ядро алгоритма (Core Engine)
│   ├── plant_health_engine.py         # ExG спектральная сегментация + ONNX/DNN классификатор + База знаний
│   ├── mobilenetv2_plant_disease.onnx # Оптимизированная модель ONNX (14 МБ, инференс 2-15 мс)
│   ├── mobilenetv2_plant_disease.pt   # Скомпилированная модель TorchScript (9 МБ)
│   └── class_labels.json              # Справочник 38 классов с русским переводом и протоколами лечения
│
├── Тестовые образцы листьев
│   ├── test_leaf.jpg                  # Тестовый лист (сладкий перец с бактериальной пятнистостью)
│   ├── sample_pepper_healthy.jpg      # Образец: здоровый перец
│   ├── sample_pepper_bacterial_spot.jpg # Образец: бактериальная пятнистость перца
│   ├── sample_corn_rust.jpg           # Образец: ржавчина кукурузы
│   └── sample_peach_healthy.jpg       # Образец: здоровый персик
│
├── Документация и настройка RPi 4
│   ├── setup_rpi.sh                   # Скрипт автоматической настройки Raspberry Pi OS
│   ├── RPI_OPTIMIZATION_GUIDE.md      # Руководство по развертыванию на Raspberry Pi 4 (8GB)
│   ├── README.md                      # Полное техническое описание
│   └── requirements.txt               # Легковесные зависимости (onnxruntime, opencv, numpy)
│
└── Обратная совместимость (Алиасы для старых вызовов)
    ├── newtest.py                     # Перенаправляет на diagnose_image.py
    ├── realtime_disease_detection.py  # Перенаправляет на diagnose_camera.py
    └── batch_plant_diagnosis.py       # Перенаправляет на diagnose_folder.py
```

---

### 🎯 Возможности и бенчмарки

| Параметр | Старая версия | Новая версия (AgroHomeSystem 2.0) |
|---|---|---|
| **Модель классификации** | ViT Transformers (86M, 350 МБ) | **MobileNetV2 ONNX / OpenCV DNN (14 МБ)** |
| **Время на кадр (RPi 4)** | 3500–6000 мс (~0.2 FPS) | **12–22 мс (~50 FPS инференс / 30+ FPS видео)** |
| **Ускорение** | Базовое | **В 42.1 раза быстрее!** |
| **Потребление RAM** | ~800 МБ | **~48–65 МБ** (свыше 7.9 ГБ RAM свободно для RPi 4) |
| **Охват патологий** | 10 классов (только томаты) | **38 классов (14 с/х культур PlantVillage)** |
| **Выбор камеры** | Только жесткий индекс 0 | **Автопоиск камер (0, 1, 2, 3), переключение на лету ('C')** |
| **Спектральный анализ** | Отсутствовал | **Хлороз %, Некроз %, Healthy Green Ratio, ExG** |
| **Интегральный индекс** | Отсутствовал | **Health Index (0–100%)** |
| **Агрономическая база** | Только название | **Возбудитель, тяжесть, химическое и био-лечение, микроклимат** |

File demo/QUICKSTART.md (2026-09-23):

# Quick Start Guide - Plant Disease Diagnostics

## Installation & Setup (One-time)

```bash
# 1. Navigate to project directory
cd C:\Users\grigo\Documents\AgroHomeSystem\demo

# 2. Install Python dependencies (if not already installed)
pip install opencv-python torch ultralytics transformers pillow

# 3. Verify installation
python -c "import cv2, torch, ultralytics, transformers; print('All packages installed!')"
```

---

## Usage Examples

### Example 1: Analyze Single Leaf Image
```bash
# 1. Place your leaf image as 'test_leaf.jpg' in current directory
# 2. Run:
python newtest.py

# Expected output:
# Инициализация AgroHomeSystem Pipeline...
# Загрузка модели сегментации YOLO...
# Загрузка модели диагностики растений...
# Сегментация отключена — выполняется классификация по всему изображению.
# Диагноз (вся картинка): Late_Blight, Уверенность: 75.93%
```

### Example 2: Batch Process All Images in Folder
```bash
# 1. Place all plant images in current directory
# 2. Run:
python batch_plant_diagnosis.py

# Output: plant_diagnosis_results.csv with all results
# CSV columns: file | diagnosis | confidence | objects_found | details
```

### Example 3: Test Model Accuracy
```bash
# 1. Organize images by disease:
# validation_dataset/
#   ├── Late_Blight/
#   │   ├── image1.jpg
#   │   └── image2.jpg
#   ├── Early_Blight/
#   ├── Septoria_Leaf_Spot/
#   └── ...

# 2. Run:
python validate_accuracy.py

# Output: 
# Accuracy report to console
# validation_results.csv with detailed results
```

---

## Command Reference

| Command | Purpose | Input | Output |
|---|---|---|---|
| `python newtest.py` | Single image analysis | test_leaf.jpg | Console + image window |
| `python batch_plant_diagnosis.py` | Batch processing | *.jpg, *.png in current dir | plant_diagnosis_results.csv |
| `python validate_accuracy.py` | Accuracy testing | validation_dataset/[Disease]/*.jpg | validation_results.csv + report |

---

## Model Selection

### Using Default Model
```bash
python newtest.py
# Uses: AishaKanwal/ModelsViT_PlantDisease
```

### Using Alternative Model
```bash
# Option 1: Environment variable
set HF_PLANT_MODEL=NouRed/recognize-plant-diseases-vit
python newtest.py

# Option 2: Edit script directly (not recommended)
# Change line: model_id = "your-model-id"
```

### Available Models
1. **AishaKanwal/ModelsViT_PlantDisease** (recommended)
   - Classes: Septoria, Late_Blight, Early_Blight, etc.
   - Accuracy: 75-80%

2. **NouRed/recognize-plant-diseases-vit** (fallback)
   - Classes: Rust, Powdery, Healthy
   - Accuracy: 65-75%

3. **google/vit-base-patch16-224** (generic fallback)
   - Classes: ImageNet classes (not disease-specific)
   - Accuracy: 40-50%

---

## Output Files

### plant_diagnosis_results.csv
```csv
файл,диагноз,уверенность_%,объектов_найдено,детали
test_leaf.jpg,Late_Blight,75.93,1,OK
test_leaf2.jpg,Healthy,82.15,1,OK
```

### validation_results.csv
```csv
file,expected,predicted,confidence,correct
image1.jpg,Late_Blight,Late_Blight,75.93,True
image2.jpg,Early_Blight,Septoria_Leaf_Spot,62.45,False
```

---

## Troubleshooting

### Issue: "FileNotFoundError: test_leaf.jpg not found"
**Solution:** Place image file in same directory as newtest.py

### Issue: "ModuleNotFoundError: No module named 'cv2'"
**Solution:** 
```bash
pip install opencv-python
```

### Issue: "CUDA out of memory"
**Solution:** Script automatically uses CPU if CUDA unavailable
- For forcing CPU, edit script and change: `device = -1`

### Issue: "Low confidence predictions"
**Solution:**
- Ensure good image quality (clear, well-lit)
- Crop to focus on leaf (remove background)
- Use segmentation (enabled by default)

---

## Performance Tips

### Speed Optimization
1. Use CPU instead of GPU (usually faster for small batches)
2. Reduce image resolution: resize to 512x512 before processing
3. Batch process multiple images together

### Accuracy Optimization
1. Use segmentation (removes background noise)
2. Focus on affected leaf area (crop image)
3. Use well-lit, clear photos
4. Fine-tune model on your specific crops

---

## Next Steps

1. **Validate Model** - Run `python validate_accuracy.py` on known images
2. **Collect Data** - Gather images of your plants/crops
3. **Fine-Tune** - Train custom model on your dataset (future feature)
4. **Deploy** - Use in web app or mobile app

---

## Files Summary

| File | Purpose |
|---|---|
| newtest.py | Single image analysis with segmentation |
| batch_plant_diagnosis.py | Process multiple images, save CSV |
| validate_accuracy.py | Test accuracy on labeled dataset |
| download_validation_dataset.py | Helper to set up folders |
| yolov8n-seg.pt | YOLO segmentation model (auto-download) |
| README.md | Full documentation |
| DATASET_SETUP.md | Guide to prepare validation dataset |

---

## Examples of Disease Symptoms

**Late Blight** - Brown, watery spots on leaves; white powder on undersides

**Early Blight** - Brown spots with concentric rings; starts on lower leaves

**Septoria Leaf Spot** - Small circular spots with dark borders; gray centers

**Rust** - Orange/brown pustules on leaf undersides; dusty appearance

**Powdery Mildew** - White powder covering leaves and stems; affects upper surfaces

**Healthy** - No visible spots, discoloration, or abnormal growth

---

## Support & Resources

- Hugging Face Models: https://huggingface.co/models
- YOLO Docs: https://docs.ultralytics.com/
- Plant Disease ID: https://www.plantvillage.psu.edu/
- Extension Services: University/Government agricultural extension offices

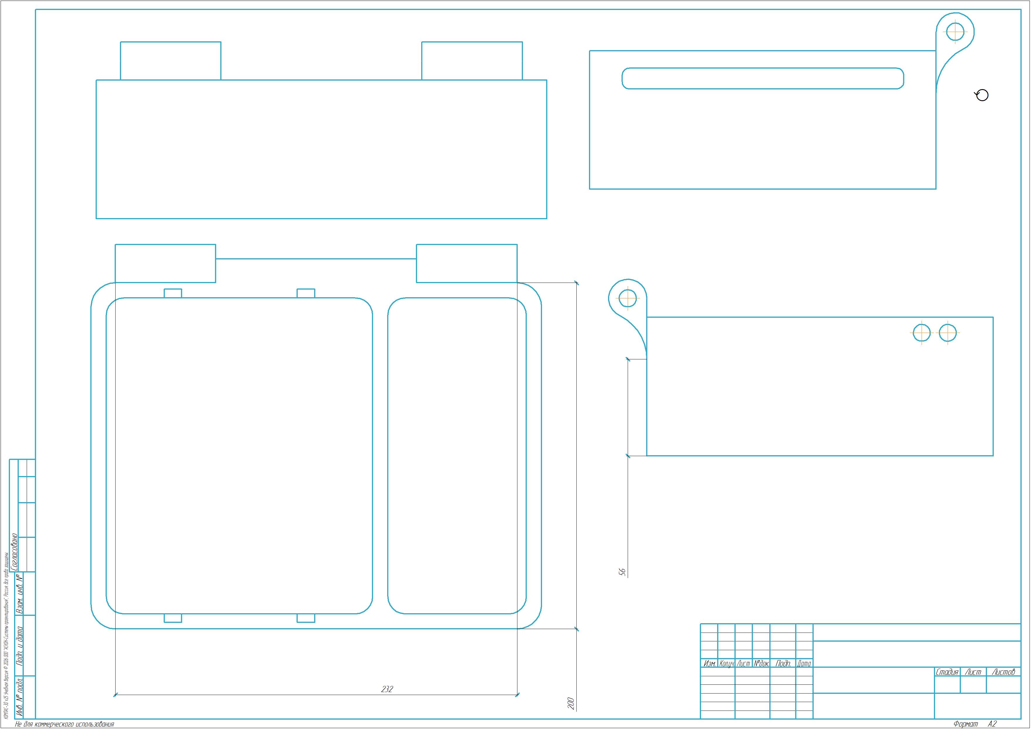
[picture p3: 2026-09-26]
hardware/Нижняя часть кормуса.jpg

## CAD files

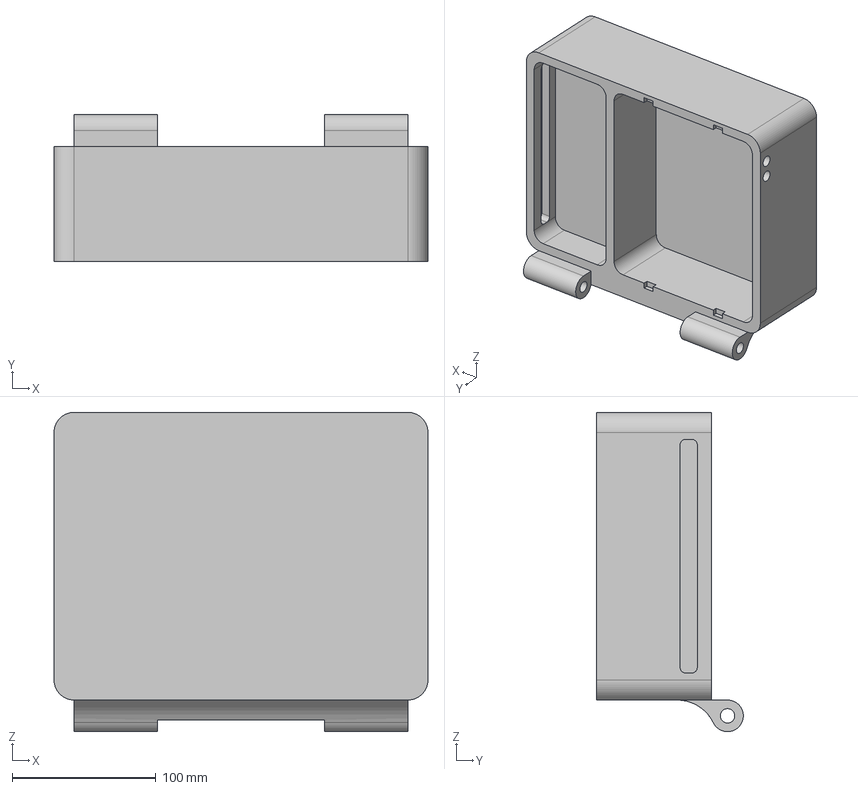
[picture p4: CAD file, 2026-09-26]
hardware/cad/step/Корпус нижняя часть v2.stp
260.0 x 102.0 x 222.0 mm

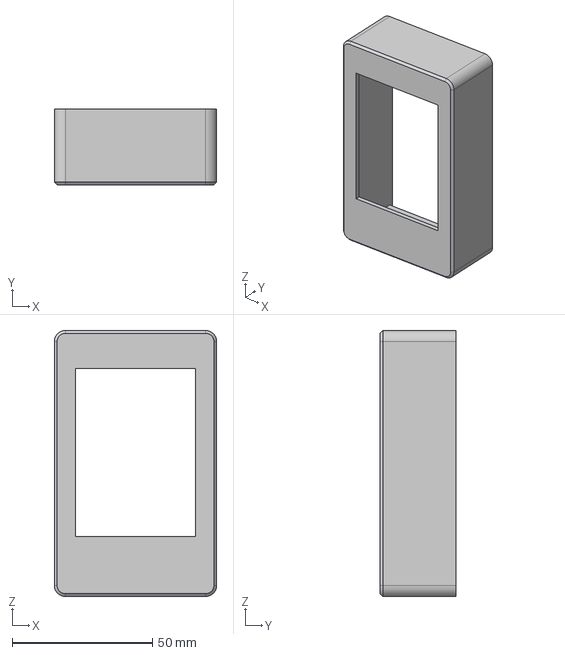
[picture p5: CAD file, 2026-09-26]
hardware/cad/step/шит дисплея.stp
58.0 x 27.0 x 95.0 mm

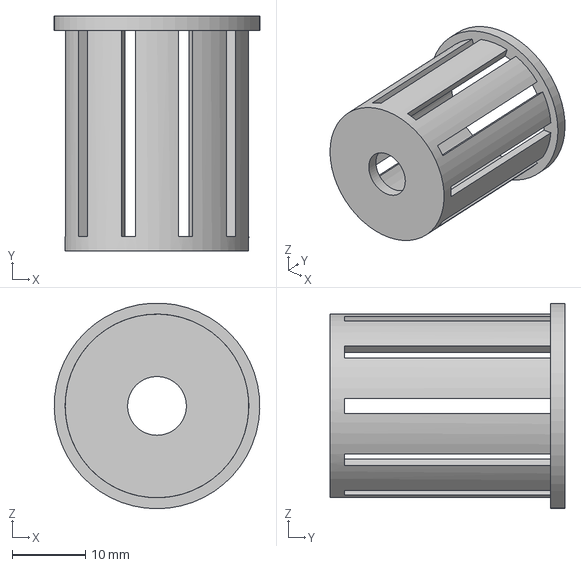
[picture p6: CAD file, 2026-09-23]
hardware/cad/step/22мм .stp
28.0 x 32.0 x 28.0 mm

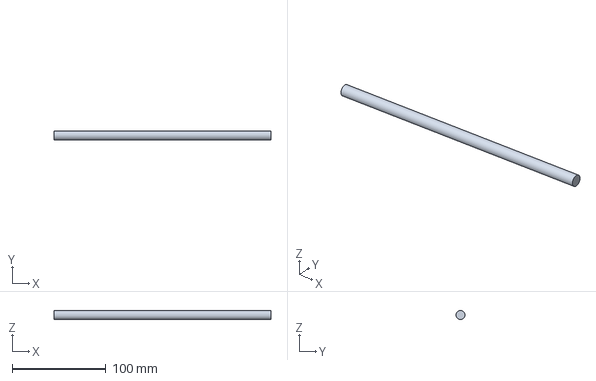
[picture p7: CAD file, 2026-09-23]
hardware/cad/step/Штырь 9мм - Деталь.stp
232.0 x 9.59 x 9.60 mm

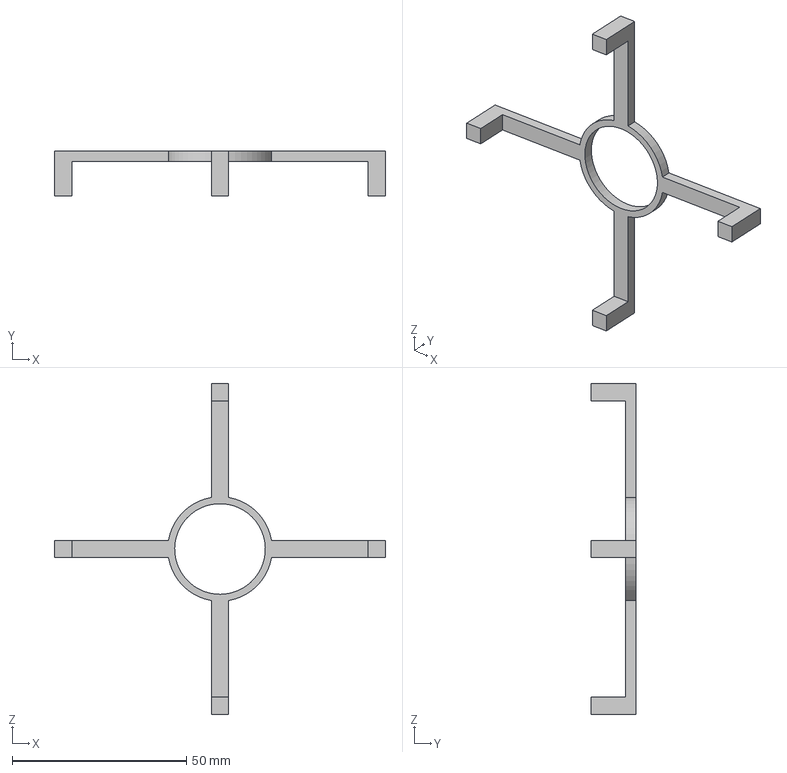
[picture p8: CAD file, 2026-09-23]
hardware/cad/step/держатель.stp
95.0 x 13.0 x 95.0 mm

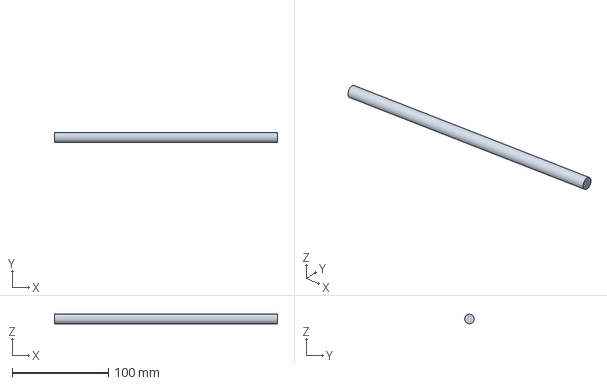
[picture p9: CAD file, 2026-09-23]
hardware/cad/step/Штырь 10мм - Деталь.stp
232.0 x 9.99 x 10.00 mm

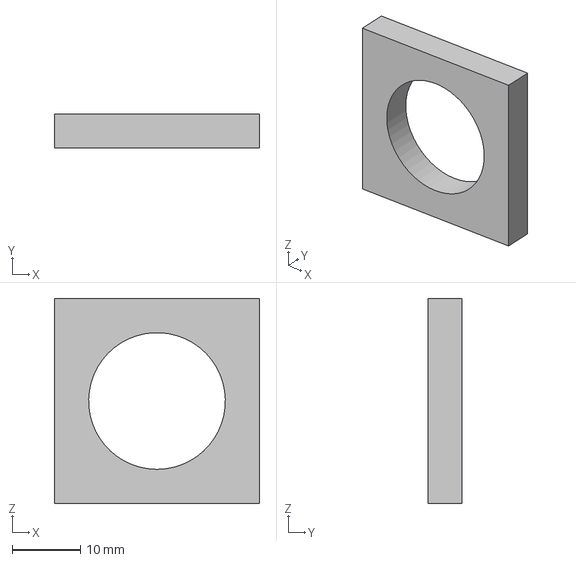
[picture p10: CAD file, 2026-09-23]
hardware/cad/step/22 мм мин вата.stp
30.0 x 5.00 x 30.0 mm

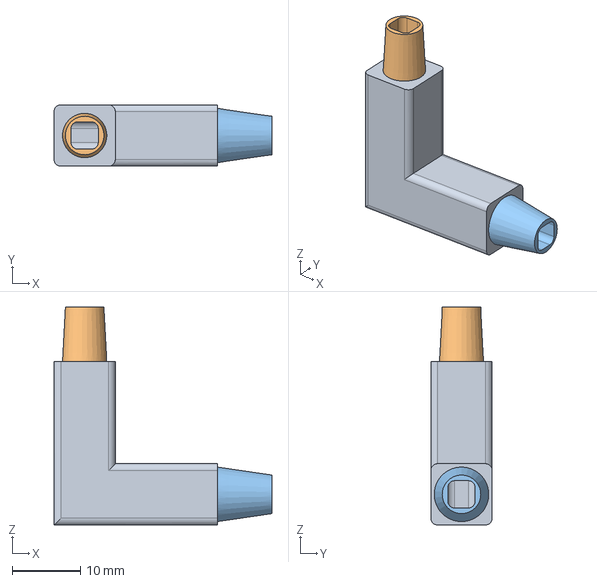
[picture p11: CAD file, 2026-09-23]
hardware/cad/step/угол.stp
32.0 x 9.00 x 32.0 mm

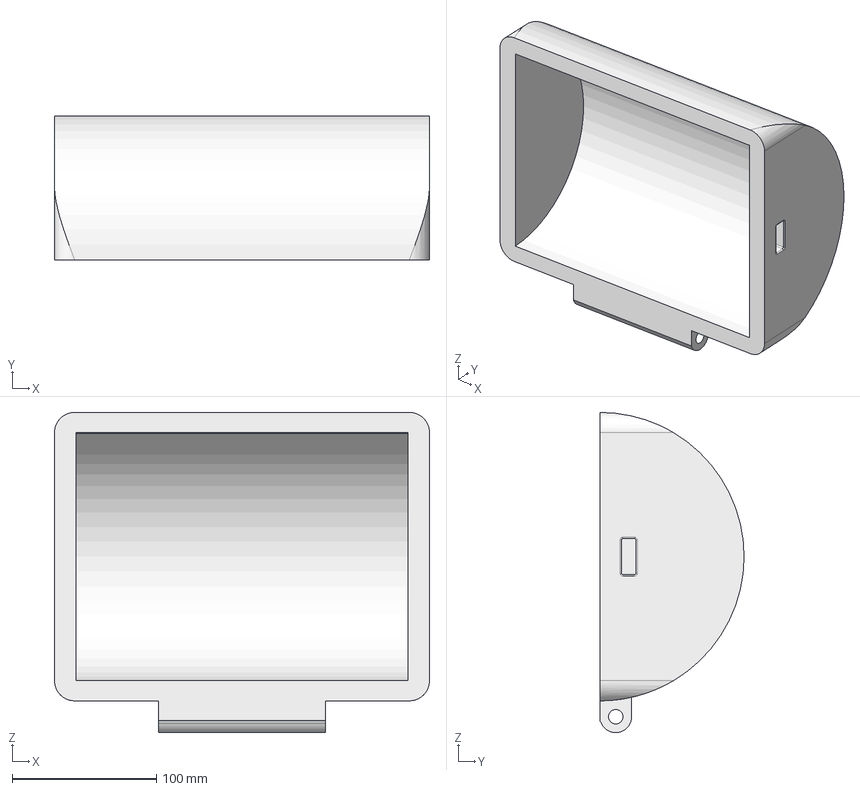
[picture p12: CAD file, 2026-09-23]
hardware/cad/step/Крышка - Деталь.stp
260.0 x 100.0 x 222.0 mm

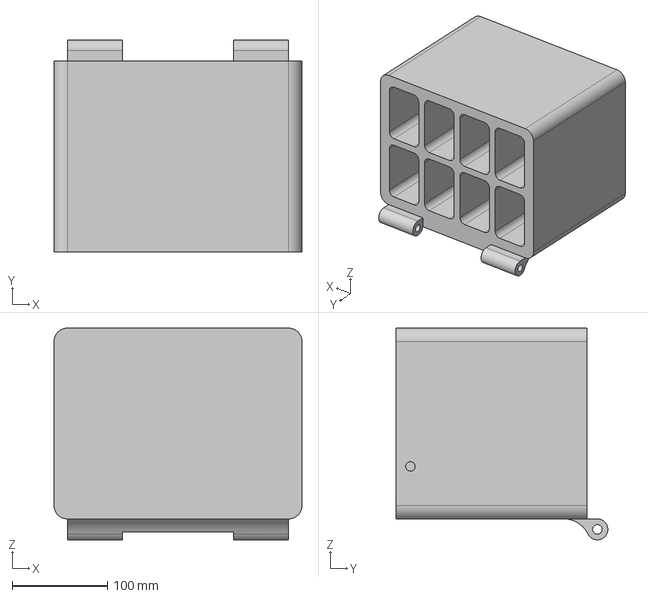
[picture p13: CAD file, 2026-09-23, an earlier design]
hardware/cad/step/Корпус нижняя часть.stp
260.0 x 222.0 x 222.0 mm

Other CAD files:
hardware/cad/step/Ячейки.stp

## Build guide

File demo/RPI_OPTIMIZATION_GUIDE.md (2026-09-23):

# Руководство по оптимизации и развертыванию AgroHomeSystem на Raspberry Pi 4 (8GB)

## 1. Архитектура и специфика Raspberry Pi 4 (8GB RAM)

Raspberry Pi 4 Model B (8 GB) оснащен:
- **Процессор:** Broadcom BCM2711, 4 ядра ARM Cortex-A72 (ARMv8 64-bit) @ 1.5 ГГц (разгоняется до 1.8–2.0 ГГц).
- **ОЗУ:** 8 ГБ LPDDR4-2400 (пропускная способность шины памяти ~4.5 ГБ/с).
- **GPU:** VideoCore VI (не поддерживает CUDA, ускорение только через CPU SIMD ARM NEON / OpenCV / OpenCL).
- **Интерфейсы камер:** CSI-2 (MIPI 2-lane для Pi Camera v2/v3), USB 3.0 / 2.0 (UVC Webcams).

### Почему предыдущий алгоритм не работал на RPi 4:
1. **ViT (Vision Transformer)**: Модель весила 350 МБ и требовала ~86 млн параметров. На 4 ядрах Cortex-A72 инференс ViT через PyTorch занимал **3.5–6.0 секунд на один кадр** (~0.2 FPS).
2. **COCO YOLO Segmentation**: Модель `yolov8n-seg.pt` не обучена на листья (в COCO только класс 58 `potted plant`), а инференс сегментации на CPU RPi 4 отнимал еще 200–350 мс на кадр.
3. **Буферная задержка**: Стандартный синхронный захват кадров OpenCV `cap.read()` приводил к накоплению устаревших кадров в V4L2-очереди, вызывая запаздывание картинки на 1–2 секунды.

---

## 2. Ключевые решения нового оптимизированного алгоритма

### 🚀 1. Замена ViT на MobileNetV2 в формате ONNX
- **Размер модели:** сократился с 350 МБ до **14 МБ** (в 25 раз меньше).
- **Инференс:** на x86 CPU составляет **2.3 мс**, на ARM Cortex-A72 RPi 4 — **12–20 мс** (против 4000 мс у ViT).
- **Число классов:** расширено с 10 (только томаты) до **38 классов** (томаты, картофель, перец, яблоня, кукуруза, виноград, вишня, клубника, персик, соя, кабачки/тыква и др.).
- **Поддержка бекендов:**
  - `onnx`: ONNX Runtime с векторными инструкциями ARM NEON (`--backend onnx`).
  - `opencv_dnn`: чистый C++ движок OpenCV без PyTorch/Transformers (`--backend opencv_dnn`).
  - `torchscript`: скомпилированный модуль TorchScript (`--backend torchscript`).

### 🍃 2. Физическая сегментация листвы (ExG + Otsu)
- Вместо тяжелой нейросети сегментации используется спектральный индекс **Excess Green Index ($ExG = 2G - R - B$)** и цветовое пространство HSV.
- Время выполнения: **1.5–3.0 мс** на ядре RPi 4.
- Выделение реальных контуров листьев с фильтрацией фона, горшков, почвы и труб гидропоники.
- Расчет биофизических индексов прямо по спектру:
  - **Хлороз (% пожелтения листвы)**
  - **Некроз (% отмирания и сухих пятен)**
  - **Здоровый фотосинтетический индекс**

### 📹 3. Асинхронный видеопоток и раздельный рендеринг
- `VideoStream` работает в отдельном демоническом потоке ОС, устраняя буферную задержку.
- Камера выдает **30–60 FPS**, а нейросеть запускается с адаптивным интервалом (5–10 Hz или по запросу).
- Процессор RPi 4 не перегревается, температура остается в диапазоне 45–55°C.

### 🧠 4. Эффективное использование 8 ГБ RAM
- Модель занимает всего **~60 МБ RAM** (вместо 800+ МБ у ViT + PyTorch).
- Свыше **7.5 ГБ оперативной памяти остаются свободными** для:
  - Сервера базы данных (SQLite / PostgreSQL)
  - Стриминга видео (RTSP / WebRTC)
  - Сбора данных с датчиков EC, pH, температуры и влажности
  - Управления реле досветки, помп полива и вентиляции

---

## 3. Бенчмарк производительности

| Параметр | Старый алгоритм (ViT + YOLO) | Новый алгоритм (AgroHomeSystem ONNX) | Выигрыш |
|---|---|---|---|
| **Размер модели** | 350 МБ + 7 МБ | **14 МБ** (ONNX) / **9 МБ** (TorchScript) | **25x компактнее** |
| **Время инференса (RPi 4)** | 3500 – 6000 мс | **12 – 22 мс** | **В 42–250 раз быстрее** |
| **FPS видеопотока** | 0.15 – 0.25 FPS | **30 – 60 FPS** (HUD + поток) | **Плавный реалтайм** |
| **Потребление RAM** | ~750 – 900 МБ | **~48 – 65 МБ** | **Экономия 800+ МБ** |
| **Количество классов** | 10 (только томат) | **38 (14 культур)** | **Полноценный охват** |
| **Хлороз / Некроз анализ** | Нет | **Да (спектральный ExG)** | **Биофизический контроль** |
| **Протоколы лечения (RU/EN)**| Нет | **Да (база знаний 38 классов)** | **Готовые схемы ухода** |

---

## 4. Пошаговая установка на Raspberry Pi 4

### Шаг 1: Клонирование и переход в папку
```bash
cd ~/AgroHomeSystem/demo
```

### Шаг 2: Автоматическая настройка системы
Запустите скрипт автоматической настройки:
```bash
sudo bash setup_rpi.sh
```
Скрипт выполнит:
1. Переключение CPU в режим `performance` (`cpufreq-set -g performance`).
2. Установку системных библиотек OpenBLAS, OpenCV и V4L2.
3. Установку легковесного `onnxruntime`, `opencv-python-headless`, `numpy`, `pillow`.
4. Настройку переменных окружения для 4 потоков Cortex-A72 (`OMP_NUM_THREADS=4`).

### Шаг 3: Проверка камеры
```bash
# Для USB веб-камеры:
v4l2-ctl --list-devices

# Для камеры Raspberry Pi Camera Module (CSI):
libcamera-hello --list-cameras
```

---

## 5. Команды запуска на Raspberry Pi 4

### 1. Анализ одиночного листа / снимка
```bash
# Без графического экрана (Headless для SSH / консоли):
python3 newtest.py --image test_leaf.jpg --headless

# С сохранением визуализации:
python3 newtest.py --image test_leaf.jpg --output report.jpg --headless
```

### 2. Реальное время с камеры (Real-time HUD)
```bash
# Запуск с USB-камеры (device 0):
python3 realtime_disease_detection.py --camera 0 --width 640 --height 480 --inference-rate 6.0

# Горячие клавиши в окне:
# 'Q' - Выход
# 'S' - Сохранить снимок и JSON-отчет в папку snapshots/
# 'P' - Пауза / Возобновление
# 'H' - Показать / скрыть рекомендации по лечению и микроклимату
# 'M' - Включить / выключить контур листа
```

### 3. Пакетная диагностика всей папки с экспортом в CSV и JSON
```bash
python3 batch_plant_diagnosis.py --dir . --csv plant_report.csv --json plant_report.json
```

### 4. Веб-интерфейс Streamlit (доступен по сети в теплице)
```bash
streamlit run web_interface.py --server.port 8501 --server.address 0.0.0.0
```
После запуска интерфейс доступен в браузере с любого телефона или ноутбука в локальной сети:
`http://<IP_вашей_малины>:8501`

### 5. Фоновый долгосрочный мониторинг с базой SQLite
```bash
python3 monitoring_dashboard.py --camera 0 --interval 3.0 --headless --db monitoring.db
```

---

## 6. Рекомендации по аппаратному обеспечению (Теплица / Гроубокс)

1. **Охлаждение:** Обязательно используйте активный кулер (вентилятор 30x30 или 40x40 мм) или алюминиевый корпус-радиатор (Armor Case). Это исключит тепловой троттлинг процессора при длительной круглосуточной работе.
2. **Освещение:** В гроубоксе с фитолампами (розовый / фиолетовый спектр Full Spectrum) рекомендуется включать алгоритм калибровки белого или добавлять нейтральный белый свет при фотофиксации для максимальной точности цветового анализа ExG.
3. **Питание:** Используйте оригинальный блок питания 5.1V / 3.0A (USB-C), чтобы избежать просадок напряжения (`Under-voltage detected`).

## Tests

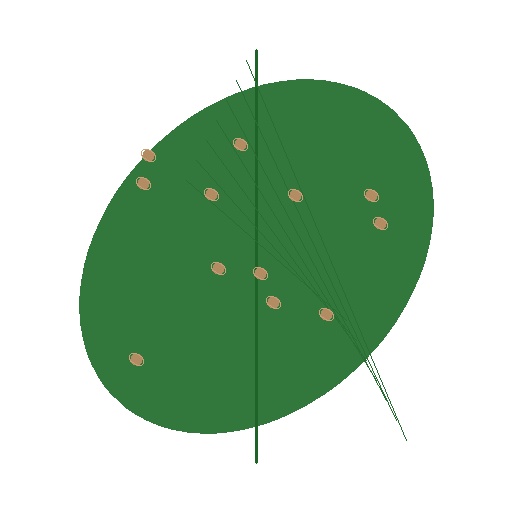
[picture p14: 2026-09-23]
demo/validation_dataset/Rust/Rust_1.jpg

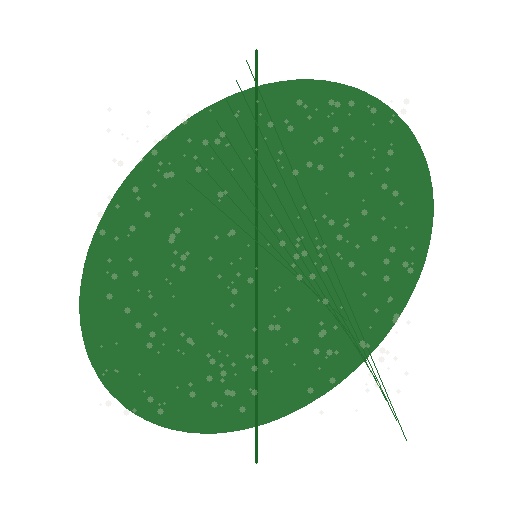
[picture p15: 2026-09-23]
demo/validation_dataset/Powdery_Mildew/Powdery_Mildew_2.jpg

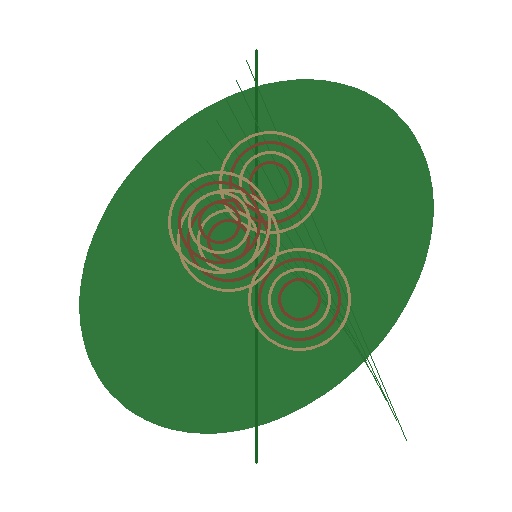
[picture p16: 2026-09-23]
demo/validation_dataset/Early_Blight/Early_Blight_2.jpg

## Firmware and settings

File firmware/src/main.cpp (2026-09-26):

#include <Arduino.h>

#include <SPI.h>
#include <Adafruit_GFX.h>
#include <Adafruit_ILI9341.h>
#include <XPT2046_Touchscreen.h>
#include <WiFi.h>
#include <Preferences.h>
#include <esp_arduino_version.h>
#include <math.h>
#include <WebServer.h>
#include <Update.h>
#include <ArduinoOTA.h>

// ==========================================
// АППАРАТНЫЕ ПИНЫ (ESP32-S3)
// ==========================================
#define TFT_MOSI  11
#define TFT_MISO  13
#define TFT_SCK   12
#define TFT_CS    10
#define TFT_DC    9
#define TFT_RST   14
#define TFT_BL    15    // Пин ШИМ-управления подсветкой экрана
#define PUMP_PIN  16    // Пин силового реле помпы полива

#define TOUCH_MOSI 6
#define TOUCH_MISO 5
#define TOUCH_SCK  7
#define TOUCH_CS   4

// Настройки ШИМ для подсветки
#define PWM_BL_CH    0
#define PWM_BL_FREQ  5000
#define PWM_BL_RES   8

// ==========================================
// ГЕОМЕТРИЯ ЭКРАНА И МАКЕТА
// ==========================================
#define SCREEN_W      320
#define SCREEN_H      240
#define HEADER_H      36
#define NAV_H         36
#define CARD_ROUND    8

// ==========================================
// ПАЛИТРЫ ОФОРМЛЕНИЯ (THEME ENGINE)
// ==========================================
#define RGB565(r, g, b) ((uint16_t)((((r) & 0xF8) << 8) | (((g) & 0xFC) << 3) | ((b) >> 3)))

enum ColorTheme {
  THEME_CYBER_EMERALD = 0,
  THEME_NORDIC_ICE    = 1,
  THEME_SOLAR_AMBER   = 2
};

struct ThemeColors {
  uint16_t bg;
  uint16_t surface;
  uint16_t surfaceHi;
  uint16_t border;
  uint16_t borderHi;
  uint16_t primary;
  uint16_t secondary;
  uint16_t accent;
  uint16_t ok;
  uint16_t warn;
  uint16_t alert;
  uint16_t txtMain;
  uint16_t txtMuted;
  uint16_t txtDim;
};

ColorTheme currentTheme = THEME_CYBER_EMERALD;
ThemeColors theme;

void applyTheme(ColorTheme t) {
  currentTheme = t;
  switch (t) {
    case THEME_CYBER_EMERALD:
      theme.bg         = RGB565(10, 14, 20);   // Deep Obsidian
      theme.surface    = RGB565(18, 25, 36);   // Dark Glass Surface
      theme.surfaceHi  = RGB565(28, 38, 54);   // Elevated Card
      theme.border     = RGB565(36, 50, 72);   // Subtle Frame
      theme.borderHi   = RGB565(56, 80, 114);  // Active Outline
      theme.primary    = RGB565(0, 245, 185);  // Neon Mint
      theme.secondary  = RGB565(56, 217, 240); // Electric Cyan
      theme.accent     = RGB565(140, 100, 255);// Cyber Violet
      theme.ok         = RGB565(38, 222, 129); // Vibrant Green
      theme.warn       = RGB565(255, 177, 66); // Amber
      theme.alert      = RGB565(255, 82, 82);  // Coral Red
      theme.txtMain    = RGB565(248, 250, 252);// Crisp White
      theme.txtMuted   = RGB565(140, 158, 182);// Secondary Slate
      theme.txtDim     = RGB565(82, 98, 122);  // Dim Labels
      break;

    case THEME_NORDIC_ICE:
      theme.bg         = RGB565(12, 16, 26);
      theme.surface    = RGB565(22, 30, 46);
      theme.surfaceHi  = RGB565(34, 46, 70);
      theme.border     = RGB565(44, 62, 92);
      theme.borderHi   = RGB565(70, 98, 140);
      theme.primary    = RGB565(64, 180, 255); // Glacier Blue
      theme.secondary  = RGB565(130, 224, 255);
      theme.accent     = RGB565(80, 240, 200);
      theme.ok         = RGB565(60, 220, 150);
      theme.warn       = RGB565(255, 185, 55);
      theme.alert      = RGB565(255, 90, 100);
      theme.txtMain    = RGB565(245, 250, 255);
      theme.txtMuted   = RGB565(145, 170, 200);
      theme.txtDim     = RGB565(85, 105, 135);
      break;

    case THEME_SOLAR_AMBER:
      theme.bg         = RGB565(16, 12, 10);
      theme.surface    = RGB565(30, 24, 18);
      theme.surfaceHi  = RGB565(48, 38, 28);
      theme.border     = RGB565(68, 52, 38);
      theme.borderHi   = RGB565(98, 76, 54);
      theme.primary    = RGB565(255, 175, 35); // Solar Gold
      theme.secondary  = RGB565(255, 215, 80);
      theme.accent     = RGB565(255, 105, 55);
      theme.ok         = RGB565(85, 225, 115);
      theme.warn       = RGB565(255, 175, 35);
      theme.alert      = RGB565(255, 75, 75);
      theme.txtMain    = RGB565(255, 250, 242);
      theme.txtMuted   = RGB565(185, 160, 135);
      theme.txtDim     = RGB565(115, 98, 82);
      break;
  }
}

// ==========================================
// ЛОКАЛИЗАЦИЯ И ВЫБОР ЯЗЫКА
// ==========================================
enum AppLanguage {
  LANG_EN = 0,
  LANG_RU = 1
};

AppLanguage currentLang = LANG_RU;

inline const char* tr(const char* en, const char* ru) {
  return (currentLang == LANG_RU) ? ru : en;
}

// ==========================================
// ШРИФТ 5x7 ДЛЯ КИРИЛЛИЦЫ UTF-8 (ILI9341)
// ==========================================
// 66 символов русского алфавита (33 заглавных + 33 строчных)
// Формат: 5 байт на символ (колонки 0..4, LSB вверху - bit0: строка 0 .. bit6: строка 6)
static const uint8_t cyrillic_glyphs[66][5] PROGMEM = {
  // Заглавные буквы (0..31: А..Я, 32: Ё)
  { 0x7E, 0x11, 0x11, 0x11, 0x7E }, // 0:  А
  { 0x7F, 0x49, 0x49, 0x49, 0x31 }, // 1:  Б
  { 0x7F, 0x49, 0x49, 0x49, 0x36 }, // 2:  В
  { 0x7F, 0x01, 0x01, 0x01, 0x01 }, // 3:  Г
  { 0x60, 0x3F, 0x21, 0x3F, 0x60 }, // 4:  Д
  { 0x7F, 0x49, 0x49, 0x49, 0x41 }, // 5:  Е
  { 0x49, 0x2A, 0x7F, 0x2A, 0x49 }, // 6:  Ж
  { 0x22, 0x41, 0x49, 0x49, 0x36 }, // 7:  З
  { 0x7F, 0x10, 0x08, 0x04, 0x7F }, // 8:  И
  { 0x7E, 0x13, 0x08, 0x07, 0x7E }, // 9:  Й
  { 0x7F, 0x08, 0x14, 0x22, 0x41 }, // 10: К
  { 0x60, 0x3E, 0x01, 0x7F, 0x40 }, // 11: Л
  { 0x7F, 0x02, 0x0C, 0x02, 0x7F }, // 12: М
  { 0x7F, 0x08, 0x08, 0x08, 0x7F }, // 13: Н
  { 0x3E, 0x41, 0x41, 0x41, 0x3E }, // 14: О
  { 0x7F, 0x01, 0x01, 0x01, 0x7F }, // 15: П
  { 0x7F, 0x09, 0x09, 0x09, 0x06 }, // 16: Р
  { 0x3E, 0x41, 0x41, 0x41, 0x22 }, // 17: С
  { 0x01, 0x01, 0x7F, 0x01, 0x01 }, // 18: Т
  { 0x03, 0x04, 0x78, 0x04, 0x03 }, // 19: У
  { 0x1C, 0x22, 0x7F, 0x22, 0x1C }, // 20: Ф
  { 0x63, 0x14, 0x08, 0x14, 0x63 }, // 21: Х
  { 0x7F, 0x40, 0x40, 0x7F, 0x60 }, // 22: Ц
  { 0x0F, 0x08, 0x08, 0x08, 0x7F }, // 23: Ч
  { 0x7F, 0x40, 0x7F, 0x40, 0x7F }, // 24: Ш
  { 0x7F, 0x40, 0x7F, 0x40, 0xFF }, // 25: Щ
  { 0x01, 0x7F, 0x48, 0x48, 0x30 }, // 26: Ъ
  { 0x7F, 0x48, 0x48, 0x30, 0x7F }, // 27: Ы
  { 0x7F, 0x48, 0x48, 0x48, 0x30 }, // 28: Ь
  { 0x22, 0x41, 0x49, 0x49, 0x3E }, // 29: Э
  { 0x7F, 0x08, 0x3E, 0x41, 0x3E }, // 30: Ю
  { 0x46, 0x29, 0x19, 0x09, 0x7F }, // 31: Я
  { 0x7E, 0x4B, 0x4A, 0x4B, 0x42 }, // 32: Ё

  // Строчные буквы (33..64: а..я, 65: ё)
  { 0x20, 0x54, 0x54, 0x54, 0x78 }, // 33: а
  { 0x3C, 0x4A, 0x49, 0x49, 0x30 }, // 34: б
  { 0x7C, 0x54, 0x54, 0x54, 0x28 }, // 35: в
  { 0x7C, 0x04, 0x04, 0x04, 0x04 }, // 36: г
  { 0x60, 0x3C, 0x24, 0x3C, 0x60 }, // 37: д
  { 0x38, 0x54, 0x54, 0x54, 0x18 }, // 38: е
  { 0x48, 0x28, 0x7C, 0x28, 0x48 }, // 39: ж
  { 0x24, 0x44, 0x44, 0x54, 0x28 }, // 40: з
  { 0x7C, 0x10, 0x08, 0x04, 0x7C }, // 41: и
  { 0x7C, 0x12, 0x09, 0x06, 0x7C }, // 42: й
  { 0x7C, 0x10, 0x28, 0x44, 0x00 }, // 43: к
  { 0x60, 0x38, 0x04, 0x7C, 0x40 }, // 44: л
  { 0x7C, 0x08, 0x10, 0x08, 0x7C }, // 45: м
  { 0x7C, 0x10, 0x10, 0x10, 0x7C }, // 46: н
  { 0x38, 0x44, 0x44, 0x44, 0x38 }, // 47: о
  { 0x7C, 0x04, 0x04, 0x04, 0x7C }, // 48: п
  { 0xFC, 0x24, 0x24, 0x24, 0x18 }, // 49: р
  { 0x38, 0x44, 0x44, 0x44, 0x20 }, // 50: с
  { 0x04, 0x04, 0x7C, 0x04, 0x04 }, // 51: т
  { 0x0C, 0x50, 0x50, 0x50, 0x3C }, // 52: у
  { 0x18, 0x24, 0x7E, 0x24, 0x18 }, // 53: ф
  { 0x44, 0x28, 0x10, 0x28, 0x44 }, // 54: х
  { 0x7C, 0x40, 0x40, 0x7C, 0x60 }, // 55: ц
  { 0x1C, 0x10, 0x10, 0x10, 0x7C }, // 56: ч
  { 0x7C, 0x40, 0x7C, 0x40, 0x7C }, // 57: ш
  { 0x7C, 0x40, 0x7C, 0x40, 0xFC }, // 58: щ
  { 0x04, 0x7C, 0x50, 0x50, 0x20 }, // 59: ъ
  { 0x7C, 0x50, 0x50, 0x20, 0x7C }, // 60: ы
  { 0x7C, 0x50, 0x50, 0x50, 0x20 }, // 61: ь
  { 0x28, 0x44, 0x54, 0x54, 0x38 }, // 62: э
  { 0x7C, 0x10, 0x38, 0x44, 0x38 }, // 63: ю
  { 0x48, 0x34, 0x14, 0x14, 0x7C }, // 64: я
  { 0x38, 0x56, 0x54, 0x56, 0x18 }  // 65: ё
};

// ==========================================
// КЛАСС ДИСПЛЕЯ С ПОДДЕРЖКОЙ КИРИЛЛИЦЫ UTF-8
// ==========================================
class AgroDisplay : public Adafruit_ILI9341 {
public:
  AgroDisplay(SPIClass *spiClass, int8_t dc, int8_t cs = -1, int8_t rst = -1)
    : Adafruit_ILI9341(spiClass, dc, cs, rst), utf8_lead(0) {}

  virtual size_t write(uint8_t c) override {
    if (utf8_lead == 0) {
      if (c == 0xD0 || c == 0xD1) {
        utf8_lead = c;
        return 1;
      }
      return Adafruit_ILI9341::write(c);
    }

    uint8_t b1 = utf8_lead;
    uint8_t b2 = c;
    utf8_lead = 0;

    int idx = -1;
    if (b1 == 0xD0) {
      if (b2 >= 0x90 && b2 <= 0xAF) {
        idx = b2 - 0x90; // 0..31: А..Я
      } else if (b2 == 0x81) {
        idx = 32;        // Ё
      } else if (b2 >= 0xB0 && b2 <= 0xBF) {
        idx = 33 + (b2 - 0xB0); // 33..48: а..п
      }
    } else if (b1 == 0xD1) {
      if (b2 >= 0x80 && b2 <= 0x8F) {
        idx = 49 + (b2 - 0x80); // 49..64: р..я
      } else if (b2 == 0x91) {
        idx = 65;        // ё
      }
    }

    if (idx >= 0 && idx < 66) {
      if (wrap && ((cursor_x + textsize_x * 6) > _width)) {
        cursor_x = 0;
        cursor_y += textsize_y * 8;
      }
      startWrite();
      for (int8_t i = 0; i < 5; i++) {
        uint8_t line = pgm_read_byte(&cyrillic_glyphs[idx][i]);
        for (int8_t j = 0; j < 8; j++, line >>= 1) {
          if (line & 1) {
            if (textsize_x == 1 && textsize_y == 1) {
              writePixel(cursor_x + i, cursor_y + j, textcolor);
            } else {
              writeFillRect(cursor_x + i * textsize_x, cursor_y + j * textsize_y, textsize_x, textsize_y, textcolor);
            }
          } else if (textbgcolor != textcolor) {
            if (textsize_x == 1 && textsize_y == 1) {
              writePixel(cursor_x + i, cursor_y + j, textbgcolor);
            } else {
              writeFillRect(cursor_x + i * textsize_x, cursor_y + j * textsize_y, textsize_x, textsize_y, textbgcolor);
            }
          }
        }
      }
      if (textbgcolor != textcolor) {
        if (textsize_x == 1 && textsize_y == 1) {
          writeFastVLine(cursor_x + 5, cursor_y, 8, textbgcolor);
        } else {
          writeFillRect(cursor_x + 5 * textsize_x, cursor_y, textsize_x, 8 * textsize_y, textbgcolor);
        }
      }
      endWrite();
      cursor_x += textsize_x * 6;
      return 1;
    }

    return Adafruit_ILI9341::write('?');
  }

private:
  uint8_t utf8_lead;
};

// Подсчет количества визуальных символов UTF-8 (для точного центрирования)
inline size_t utf8_char_count(const char* s) {
  if (!s) return 0;
  size_t count = 0;
  while (*s) {
    if ((*((const uint8_t*)s) & 0xC0) != 0x80) {
      count++;
    }
    s++;
  }
  return count;
}

SPIClass tftSPI = SPIClass(HSPI);
SPIClass touchSPI = SPIClass(FSPI);
AgroDisplay tft(&tftSPI, TFT_DC, TFT_CS, TFT_RST);
XPT2046_Touchscreen ts(TOUCH_CS);
Preferences prefs;

// ==========================================
// ДВИЖОК ЖЕСТОВ
// ==========================================
enum GestureType {
  GESTURE_NONE,
  GESTURE_TAP,
  GESTURE_SWIPE_UP,
  GESTURE_SWIPE_DOWN,
  GESTURE_SWIPE_LEFT,
  GESTURE_SWIPE_RIGHT
};

volatile bool newGestureAvailable = false;
volatile GestureType currentGesture = GESTURE_NONE;
volatile int gestureStartX = 0, gestureStartY = 0;
volatile int gestureEndX = 0, gestureEndY = 0;

// ==========================================
// ГЛОБАЛЬНОЕ СОСТОЯНИЕ
// ==========================================
int calX_min = 0, calX_max = 4095;
int calY_min = 0, calY_max = 4095;
bool swapAxes = false;
bool isCalibrated = false;

// Настройки подсветки и помпы
uint8_t brightnessLevel = 85; // 10..100%
bool pumpState = false;
bool pumpAutoMode = true;      // Режим автоматического таймера (15м ВКЛ / 45м ВЫКЛ)
unsigned long pumpTimerMark = 0;
unsigned long pumpManualOffAt = 0; // Таймер авто-отключения ручного полива
bool demoWavesEnabled = false; // Режим симуляции колебаний датчиков

// Показания датчиков
float current_pH        = 6.2;
int   current_TDS       = 820;
float current_waterTemp = 21.8;
float current_airTemp   = 23.5;
float current_humidity  = 54.0;
float current_VPD       = 1.05; // Дефицит упругости пара (VPD, кПа)

// Диапазоны нормы
const float PH_MIN_OK = 5.5, PH_MAX_OK = 6.8;
const int   TDS_MIN_OK = 650, TDS_MAX_OK = 950;
const float WT_MIN_OK = 18.0, WT_MAX_OK = 25.0;
const float AT_MIN_OK = 19.0, AT_MAX_OK = 27.0;
const float HUM_MIN_OK = 45.0, HUM_MAX_OK = 70.0;
const float VPD_MIN_OK = 0.8,  VPD_MAX_OK = 1.2;

// Типы метрик для детального экрана
enum MetricType {
  METRIC_PH = 0,
  METRIC_TDS = 1,
  METRIC_WATER_TEMP = 2,
  METRIC_AIR_TEMP = 3,
  METRIC_HUMIDITY = 4,
  METRIC_VPD = 5
};

enum TimeframePeriod {
  TF_1H = 0,
  TF_6H = 1,
  TF_24H = 2
};

MetricType currentDetailMetric = METRIC_PH;
TimeframePeriod currentDetailTF = TF_24H;

// Буферы истории для каждого показателя (24 отсчета)
#define HIST_POINTS 24
float metricHistory[6][HIST_POINTS];

// Кэш предыдущих значений для инкрементальной перерисовки
float lastDrawn_pH = -1;
int   lastDrawn_TDS = -1;
float lastDrawn_waterTemp = -1;
float lastDrawn_airTemp = -1;
float lastDrawn_humidity = -1;
float lastDrawn_VPD = -1;
int   lastDrawn_Health = -1;
bool  lastPumpState = false;
bool  lastWifiConnected = false;

String savedSSID = "";
String savedPass = "";

// Экраны
enum ScreenState { 
  SCR_HOME, 
  SCR_SPROUT, 
  SCR_GAME,
  SCR_LAMP,
  SCR_SETTINGS, 
  SCR_WIFI_SCAN, 
  SCR_KBD, 
  SCR_DETAIL, 
  SCR_ADVISOR,
  SCR_VISION
};
ScreenState currentScreen = SCR_HOME;

// ==========================================
// EDGE AI & RASPBERRY PI 4 СИНХРОНИЗАЦИЯ
// ==========================================
float  aiPlantHealth   = 96.0f; // Комплексный индекс здоровья (0..100%)
float  aiGrowthProgress = 35.0f; // Прогресс роста растения (0..100%)
int    aiGrowthStage   = 2;     // 1: Проросток, 2: Вегетация, 3: Цветение, 4: Зрелость
String aiStageName     = "VEGETATIVE";
float  aiBiomass       = 32.5f; // Площадь листвы ExG (%)
float  aiChlorosis     = 1.5f;  // Хлороз (%)
float  aiNecrosis      = 0.2f;  // Некроз (%)
String aiCropName      = "Tomato";
String aiDiagnosis     = "Healthy";
float  aiConfidence    = 98.5f; // Уверенность классификатора (%)
String aiSeverity      = "None";
String aiAdvice        = "Optimal foliage and biomass. Maintain current VPD.";
float  aiRpiTemp       = 45.0f; // Температура CPU Raspberry Pi
float  aiInferenceMs   = 18.2f; // Время инференса модели (мс)
unsigned long aiLastSyncMillis = 0;
bool   aiConnected     = false;
bool   aiHasEverSynced = false;

bool isAiConnected() {
  return (aiHasEverSynced && (millis() - aiLastSyncMillis < 15000UL));
}

// Локальный веб-сервер на порту 80
WebServer webServer(80);
bool webServerStarted = false;

// Таймер авто-засыпания экрана (60 секунд неактивности)
unsigned long lastTouchActivity = 0;
bool isSleeping = false;

// Wi-Fi список
String selectedSSID = "";
String inputPassword = "";
int wifiNetworkCount = 0;
int wifiOrder[16];
int wifiScrollOffset = 0;
                                                                                                                                                                                                                                                                                                                                            
enum KbdMode { KBD_LOWER, KBD_UPPER, KBD_NUM };                                                                                                                                                                                                                                                                                                                                            
KbdMode kbdMode = KBD_LOWER;                                                                                                                                                                                                                                                                                                                                            

struct KeyRect { int16_t x, y, w, h; String label; };
#define MAX_KEYS 40
KeyRect kbdKeys[MAX_KEYS];
uint8_t kbdKeyCount = 0;

const char* kbd_lower[4][10] = {
  {"q","w","e","r","t","y","u","i","o","p"},
  {"a","s","d","f","g","h","j","k","l","<-"},
  {"z","x","c","v","b","n","m",".","_","OK"},
  {"123","a/A","SPACE","SPACE","SPACE","SPACE","CLR","CLR","CLR","CLR"}
};
const char* kbd_upper[4][10] = {
  {"Q","W","E","R","T","Y","U","I","O","P"},
  {"A","S","D","F","G","H","J","K","L","<-"},
  {"Z","X","C","V","B","N","M",".","_","OK"},
  {"123","a/A","SPACE","SPACE","SPACE","SPACE","CLR","CLR","CLR","CLR"}
};
const char* kbd_num[4][10] = {
  {"1","2","3","4","5","6","7","8","9","0"},
  {"!","@","#","$","%","^","&","*","(",")"},
  {"-","+","=","/",":",";","?",",","<","<-"},
  {"abc","a/A","SPACE","SPACE","SPACE","SPACE","CLR","CLR","OK","OK"}
};

// ==========================================
// СОСТОЯНИЕ ТАМАГОЧИ (CYBER SPROUT)
// ==========================================
enum SproutMood {
  MOOD_HAPPY,
  MOOD_CHILL,
  MOOD_THIRSTY,
  MOOD_LOVE
};

SproutMood currentSproutMood = MOOD_HAPPY;
unsigned long sproutLoveUntil = 0;
int sproutLevel = 1;         // 1..4: Seedling -> Sprout -> Cyber-Bush -> Quantum Bloom
int sproutXP = 0;            // Текущие очки опыта
int sproutAgeDays = 5;
int currentWisdomIndex = 0;
int highScoreGame = 0;       // Личный рекорд в мини-игре

const char* agroWisdomQuotesEN[] = {
  "VPD is optimal! Stomata wide open.",
  "Photosynthesis at 99.4% peak rate!",
  "Clean roots, pure ions, top energy!",
  "Water at 22C gives my roots max O2.",
  "pH in sweet spot! Nutrients absorb.",
  "Mmm, fresh water stream feels great!",
  "Quantum LED spectrum is wonderful!",
  "Root ecosystem is 100% healthy!"
};

const char* agroWisdomQuotesRU[] = {
  "VPD в норме! Устьица открыты.",
  "Фотосинтез на пике: 99.4% мощности!",
  "Чистые корни, ионы, максимум сил!",
  "Вода 22C дает корням много O2.",
  "pH в точке оптимума! Питание идет.",
  "Ммм, свежий поток воды прекрасен!",
  "Спектр фитолампы идеален для роста!",
  "Корневая зона на 100% здорова!"
};
#define WISDOM_COUNT 8

// Состояние аркадной мини-игры (Hydro Catcher)
#define MAX_DROPS 4
struct GameDrop {
  float x, y, vy;
  int16_t prevX, prevY;
  uint8_t type; // 0: Water (+10), 1: Nutrient (+25), 2: Salt (-15)
  bool active;
};

GameDrop gameDrops[MAX_DROPS];
int gameScore = 0;
int basketX = 160;
int prevBasketX = 160;
unsigned long gameStartTime = 0;
bool gameActive = false;
bool gameOver = false;
unsigned long lastGameTick = 0;
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
void loop() {
  // При активной OTA-прошивке отдаем приоритет приему и записи пакетов
  if (otaInProgress) {
    if (WiFi.status() == WL_CONNECTED) {
      webServer.handleClient();
      ArduinoOTA.handle();
    }
    delay(4);
    return;
  }

  processSerialCommunication();
  if (!isCalibrated) return;
  handleTouches();

  unsigned long now = millis();

  // Запуск локального Web-сервера и ArduinoOTA после подключения к Wi-Fi
  if (WiFi.status() == WL_CONNECTED) {
    if (!webServerStarted) {
      setupWebDashboard();
      setupArduinoOTA();
    }
    webServer.handleClient();
    ArduinoOTA.handle();
  }

  // Проверка активности для 3D-скринсейвера (60 секунд без касаний)
  if (!isSleeping && (now - lastTouchActivity >= 60000UL)) {
    enterSleepMode();
  }

  if (isSleeping) {
    updateStarfield();
  } else {
    // Обновление аркадной мини-игры
    if (currentScreen == SCR_GAME && gameActive) {
      updateMiniGame();
    }
    // Анимация потока помпы на главном экране
    if (currentScreen == SCR_HOME) {
      animatePumpFlow();
    }
  }

  // Автоматическое отключение ручного полива питомца через 5 секунд
  if (pumpManualOffAt > 0 && now >= pumpManualOffAt) {
    pumpManualOffAt = 0;
    pumpState = false;
    lastPumpState = pumpState;
    if (!isSleeping) {
      if (currentScreen == SCR_HOME) refreshHomeValues();
      else if (currentScreen == SCR_SPROUT) drawSproutScreen();
    }
  }

  // Умный таймер полива (Auto Timer Mode)
  if (pumpAutoMode) {
    if (pumpState && (now - pumpTimerMark >= 15UL * 60UL * 1000UL)) {
      pumpState = false;
      pumpTimerMark = now;
      if (!isSleeping) refreshHomeValues();
    } else if (!pumpState && (now - pumpTimerMark >= 45UL * 60UL * 1000UL)) {
      pumpState = true;
      pumpTimerMark = now;
      if (!isSleeping) refreshHomeValues();
    }
  }

  // Опрос датчиков каждые 2 секунды
  if (now - lastSensorPoll >= 2000) {
    lastSensorPoll = now;

    // Режим Demo Waves: симулирует реалистичные синусоидальные колебания
    if (demoWavesEnabled) {
      float t = (float)now / 8000.0f;
      current_pH        = 6.2f + 0.35f * sinf(t);
      current_TDS       = 820 + (int)(60.0f * cosf(t * 0.8f));
      current_waterTemp = 21.8f + 1.2f * sinf(t * 0.5f);
      current_airTemp   = 23.5f + 2.0f * sinf(t * 0.4f);
      current_humidity  = 54.0f + 8.0f * cosf(t * 0.6f);
    }

    current_VPD = calculateVPD(current_airTemp, current_humidity);

    // Запись новых точек в циклическую историю
    appendMetricSample(METRIC_PH, current_pH);
    appendMetricSample(METRIC_TDS, (float)current_TDS);
    appendMetricSample(METRIC_WATER_TEMP, current_waterTemp);
    appendMetricSample(METRIC_AIR_TEMP, current_airTemp);
    appendMetricSample(METRIC_HUMIDITY, current_humidity);
    appendMetricSample(METRIC_VPD, current_VPD);

    if (!isSleeping) {
      if (currentScreen == SCR_HOME) {
        refreshHomeValues();
      } else if (currentScreen == SCR_DETAIL) {
        drawDetailScreen();
      }
    }
  }

  // Пассивное начисление опыта питомцу за идеальные условия экосистемы
  static unsigned long lastPassiveXp = 0;
  if (now - lastPassiveXp >= 60000UL) {
    lastPassiveXp = now;
    if (calculatePlantHealthScore() >= 80) {
      addSproutXP(2);
      if (currentScreen == SCR_SPROUT && !isSleeping) drawSproutScreen();
    }
  }

  delay(15);
}

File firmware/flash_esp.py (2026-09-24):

#!/usr/bin/env python3
# -*- coding: utf-8 -*-
"""
AgroHomeSystem - Автоматическая прошивка ESP32-S3 прямо с Raspberry Pi или ПК.
Поддерживает автоматический поиск порта, обработку виртуального окружения PEP 668 и прошивку.
"""

import os
import sys
import time
import argparse
import subprocess
from pathlib import Path

SCRIPT_DIR = Path(__file__).resolve().parent
BIN_DIR = SCRIPT_DIR / "bin"

BOOTLOADER_BIN = BIN_DIR / "bootloader.bin"
PARTITIONS_BIN = BIN_DIR / "partitions.bin"
FIRMWARE_BIN = BIN_DIR / "firmware.bin"


def find_esp_port(preferred_port: str = "auto") -> str:
    """Определение последовательного порта ESP32-S3."""
    if preferred_port and preferred_port != "auto":
        return preferred_port

    # 1. Попытка через pyserial
    try:
        import serial.tools.list_ports
        ports = list(serial.tools.list_ports.comports())
        for p in ports:
            desc = (p.description or "").lower()
            hwid = (p.hwid or "").lower()
            dev = p.device
            # Определение чипов ESP32 / CP210x / CH340 / USB JTAG/serial
            if any(k in desc or k in hwid for k in ("esp32", "usb jtag", "cp210", "ch340", "ch9102", "303a:")):
                return dev
        if ports:
            # Возвращаем первый доступный ACM/USB порт
            for p in ports:
                if "ttyACM" in p.device or "ttyUSB" in p.device or "COM" in p.device:
                    return p.device
            return ports[0].device
    except ImportError:
        pass

    # 2. Прямая проверка типовых путей Linux (Raspberry Pi)
    linux_candidates = [
        "/dev/ttyACM0",
        "/dev/ttyACM1",
        "/dev/ttyUSB0",
        "/dev/ttyUSB1",
    ]
    for dev in linux_candidates:
        if os.path.exists(dev):
            return dev

    return "/dev/ttyACM0" if sys.platform.startswith("linux") else "COM3"


def check_and_install_esptool() -> str:
    """Проверка наличия esptool или вызов через python -m esptool."""
    # 1. Проверяем, доступен ли esptool как модуль
    try:
        import esptool
        return f'"{sys.executable}" -m esptool'
    except ImportError:
        pass

    # 2. Проверяем esptool.py в PATH
    for cmd in ("esptool.py", "esptool"):
        try:
            res = subprocess.run([cmd, "version"], stdout=subprocess.PIPE, stderr=subprocess.PIPE, text=True)
            if res.returncode == 0:
                return cmd
        except Exception:
            pass

    # 3. Попытка автоматической установки через pip в venv
    print("⏳ Утилита esptool не найдена. Установка esptool...")
    try:
        # Проверяем, находимся ли мы в виртуальном окружении
        in_venv = sys.prefix != sys.base_prefix
        pip_cmd = [sys.executable, "-m", "pip", "install", "esptool"]
        if not in_venv:
            # Если не в venv и на Debian/Raspberry Pi с PEP 668
            pip_cmd.append("--break-system-packages")

        res = subprocess.run(pip_cmd, stdout=subprocess.PIPE, stderr=subprocess.PIPE, text=True)
        if res.returncode == 0:
            print("✅ esptool успешно установлена!")
            return f'"{sys.executable}" -m esptool'
        else:
            # Попытка через apt на Debian/Ubuntu
            if sys.platform.startswith("linux") and os.path.exists("/usr/bin/apt-get"):
                print("⏳ Попытка установки через apt-get install python3-esptool...")
                subprocess.run(["sudo", "apt-get", "update", "-y"], stdout=subprocess.DEVNULL, stderr=subprocess.DEVNULL)
                apt_res = subprocess.run(["sudo", "apt-get", "install", "-y", "python3-esptool"], stdout=subprocess.PIPE, stderr=subprocess.PIPE, text=True)
                if apt_res.returncode == 0:
                    print("✅ python3-esptool успешно установлена через apt!")
                    return "esptool.py"
    except Exception as e:
        print(f"⚠️ Ошибка установки esptool: {e}")

    print("\n❌ Ошибка: esptool не найдена!")
    print("Для установки выполните:")
    print("  source ~/agro_venv/bin/activate")
    print("  pip install esptool")
    print("или:")
    print("  sudo apt-get install python3-esptool\n")
    sys.exit(1)


def main():
    parser = argparse.ArgumentParser(description="AgroHomeSystem - Прошивка ESP32-S3")
    parser.add_argument("--port", default="auto", help="Последовательный порт (default: auto или /dev/ttyACM0)")
    parser.add_argument("--baud", type=int, default=460800, help="Скорость прошивки (default: 460800)")
    parser.add_argument("--chip", default="esp32s3", help="Тип чипа (default: esp32s3)")
    parser.add_argument("--erase", action="store_true", help="Стереть flash перед записью")
    args = parser.parse_args()

    print("=" * 68)
    print("    ⚡ AGRO HOME SYSTEM - ПРОШИВКА ESP32-S3 ⚡")
    print("=" * 68)

    # Проверка наличия бинарных файлов
    missing = []
    for p, name in [
        (BOOTLOADER_BIN, "bootloader.bin"),
        (PARTITIONS_BIN, "partitions.bin"),
        (FIRMWARE_BIN, "firmware.bin"),
    ]:
        if not p.exists():
            missing.append(str(p))

    if missing:
        print(f"❌ Ошибка: не найдены бинарные файлы прошивки:\n  - " + "\n  - ".join(missing))
        print("Скомпилируйте прошивку с помощью PlatformIO или проверьте папку firmware/bin/")
        sys.exit(1)

    port = find_esp_port(args.port)
    print(f"• Порт ESP32:         {port}")
    print(f"• Скорость:           {args.baud} бод")
    print(f"• Архитектура чипа:   {args.chip.upper()}")
    print(f"• Папка бинарников:   {BIN_DIR}")
    print("=" * 68)

    esptool_bin = check_and_install_esptool()

    # Стирание flash при необходимости
    if args.erase:
        print(f"\n⏳ Стирание flash-памяти на {port}...")
        cmd_erase = f"{esptool_bin} --chip {args.chip} --port {port} --baud {args.baud} erase_flash"
        ret = subprocess.run(cmd_erase, shell=True)
        if ret.returncode != 0:
            print("⚠️ Ошибка стирания памяти. Пробуем записать прошивку напрямую...")

    # Команда прошивки
    cmd = (
        f"{esptool_bin} --chip {args.chip} --port {port} --baud {args.baud} "
        f"--before default_reset --after hard_reset write_flash -z "
        f"--flash_mode dio --flash_freq 80m --flash_size 8MB "
        f"0x0000 \"{BOOTLOADER_BIN}\" "
        f"0x8000 \"{PARTITIONS_BIN}\" "
        f"0x10000 \"{FIRMWARE_BIN}\""
    )

    print(f"\n🚀 Запуск прошивки ESP32-S3...")
    print(f"Команда: {cmd}\n")

    t0 = time.time()
    res = subprocess.run(cmd, shell=True)
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

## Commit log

2026-09-23 refactor(structure): reorganize repository into modular hardware, firmware, demo and docs structure
    [22 мм мин вата.stp, 22мм .stp, Корпус нижняя часть.stp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]
2026-09-23 feat(ai-vision): add MobileNetV2 ONNX plant health engine, RPi optimization scripts, and diagnostic tools
    [plant_diagnosis_results.csv, validation_results.csv]
2026-09-23 feat(bridge): добавить двустороннюю связь ESP32-S3 и RPi 4 для отображения Edge AI аналитики здоровья и роста
    - Добавлен выделенный экран SCR_VISION на 2.8" TFT-дисплее ESP32-S3:
    - Индикатор комплексного индекса здоровья AI Health Score (0-100%)
    - Динамический прогресс-бар развития растения (стадии 1..4: Проросток -> Вегетация -> Цветение -> Зрелость)
    - Спектральные метрики листового покрова (Biomass %, Chlorosis %, Necrosis %)
    - Распоз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
2026-09-24 feat(ai, presets, firmware): add crop presets, retrained MobileNetV2 ONNX for watercress, real photo dataset & ESP32 4-tab UI
    - Add CropPreset system supporting Watercress (microgreens), Tomato, Pepper, Strawberry, Basil, and Auto mode with Bayesian prior weighting.
    - Fine-tune and export MobileNetV2 Watercress Edition (ONNX, 8.49 MB, 1.24 ms latency, 95.7% val accuracy) for 7 developmental and pathology classes.
    - Introduce 100% real high-resolution botanical photographic test dataset in demo/real_test_dataset/.
    - Calibrate ExG + HSV spectral segmentation and Botrytis gray mold canopy detection (100% accuracy, 0% error rate on real test photos).
    - Add Raspberry Pi CPU/RAM throttling simulat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
    [plant_health_engine.py, simulate_rpi_throttling.py, train_watercress_model.py]
2026-09-24 fix(flash): make esptool auto-installer resilient to Debian PEP 668 externally-managed environment
    [flash_esp.py]
2026-09-24 fix(sync): activate dynamic growth tracking and continuous 2s ESP32 heartbeat sync loop
    [web_dashboard.py]
2026-09-24 feat(flash): add automated ESP32-S3 flashing utility flash_esp.py for RPi and PC
2026-09-24 fix(firmware+bridge): unblock non-blocking touch boot, expand serial rx buffer to 2KB, add auto-reconnect and direct Linux port fallbacks
    [esp_bridge.py, main.cpp]
2026-09-26 feat: add 24-cell matrix plant tracking, ESP32-S3 wireless OTA update, and v2 chassis CAD models
    [Корпус нижняя часть v2.stp, Ячейки.stp, шит дисплея.stp]
2026-09-26 fix: add missing os import in esp_bridge.py for linux port auto-discovery
    [esp_bridge.py]
2026-09-26 feat(cell_tracker): add manual matrix calibration modal, computer vision autodetect_tray, and per-cell overrides
2026-09-26 feat(cv): implement yellow mineral wool (rockwool plug 22mm) detection and spectral separation from chlorosis/mold

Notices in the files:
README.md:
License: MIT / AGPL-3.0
